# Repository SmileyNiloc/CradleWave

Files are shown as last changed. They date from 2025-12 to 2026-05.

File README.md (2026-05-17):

# CradleWave: Contactless Infant Vitals Monitoring 🍼📡


[]()
[]()
[]()
[]()

**CradleWave** is an end-to-end IoT monitoring system that leverages 60 GHz FMCW radar to measure an infant's heart rate and respiration—completely avoiding the privacy concerns and physical discomfort of traditional cameras, microphones, or wearables.

This repository contains the complete systems engineering effort encompassing a custom 4-layer PCB, ESP32-S3 FreeRTOS firmware, a containerized Python digital signal processing (DSP) pipeline, and a real-time Vue 3 dashboard.

## 🚀 Tech Stack Highlights

- **Hardware & Firmware:** ESP32-S3, Infineon XENSIV 60GHz Radar (BGT60TR13C), Custom 4-Layer PCB, C/C++, ESP-IDF, FreeRTOS
- **DSP & Data Pipeline:** Python (NumPy, SciPy), Docker Compose microservices, Redis, AWS IoT Core (MQTT over TLS)
- **Frontend & Database:** Vue 3, ECharts, Google Firestore, Firebase Hosting

## 💡 The Problem & Our Solution

Each year, thousands of infants in the US are affected by SIDS or sleep-related suffocation. Existing monitors are often uncomfortable, inconvenient, or limited in vital-sign coverage.

CradleWave targets contactless, continuous monitoring from a safe distance. The final prototype integrates an Infineon BGT60TR13C radar shield with a custom ESP32-S3 PCB to stream raw multi-dimensional radar data over WiFi. The data is processed via an algorithmic pipeline in the cloud to extract physiological vitals, which are then surfaced on a responsive web UI.

### Key Engineering Achievements

- Developed a high-bandwidth IoT pipeline using MQTT/TLS to stream raw binary radar data asynchronously from an ESP32 to AWS IoT Core.
- Built a multi-container Docker compose DSP microservice, orchestrating Python with Redis to filter out environmental noise.
- Designed and verified an algorithmic pipeline (using FFT, moving target indicators, and bandpass filters) that calculates BPM/RPM to +-5/+-3 accuracy points from noisy FMCW data.
- Built an end-to-end Vue.js SPA dynamically synced via Firestore, handling real-time data visualisations of signals at sub-second refresh rates.

## System Architecture

```mermaid
flowchart TD
    %% Clinical Calm Theme - Green Dominant
    classDef default fill:#CEE4C7,stroke:#FFFFFF,stroke-width:3px,color:#334155
    classDef storage fill:#F8F9F5,stroke:#CEE4C7,stroke-width:3px,color:#334155

    %% Style the connecting arrows to match the theme
    linkStyle default stroke:#A8CBA0,stroke-width:2px,color:#334155

    A["`**ESP32 Radar**
    Hardware sensor node collecting raw data`"] -->|Publish MQTT Message| B["`**AWS IoT Core MQTT**
    Managed cloud broker receiving data`"]

    B -->|Subscribed to MQTT topic| C("`**Ingestor Node**
    Retrieves and buffers incoming payloads`")

    C -->|Queued Frames| R("`**Redis**
    In-Memory Storage Container`")

    R -->|Queued Frames| D("`**Processor Node**
    Runs Signal Processing to find vitals signs`")

    D -->|Vital Signs| R

    R -->|Vitals Signs| E("`**Exporter Node**
    Formats output for database ingestion`")

    E -->|Write/Update| F[("`**Firestore Database**
    NoSQL document store for vital signs data`")]

    F -->|Real-Time Sync| G["`**Vue.js Web Dashboard**
    Frontend UI displaying live analytics`"]

    %% Apply storage theme to databases
    class R,F storage
```

## 🏗️ Project Architecture & Repositories

```
CradleWave/
├── CAD_Designs/                # Fusion360 3D Enclosure Designs
├── station_example_main.c      # ESP-IDF FreeRTOS Firmware Logic (Radar SPI + WiFi + MQTT)
├── local_testing/              # Local Docker Compose setup for iterating on MQTT and signal loops
├── mqtt_test/                  # Raw payload tests and Python MQTT test scripts
├── demo_board_python/          # (Legacy) Initial prototype using Infineon demo board + Raspberry Pi
│
└── webdev/
    ├── backend/                # Python / Docker Compose Pipeline
    │   ├── ingestor/           # AWS IoT MQTT Handler
    │   ├── processor/          # DSP Pipeline (SciPy, FFT, filtering)
    │   └── exporter/           # Formatting & Firestore synchronization
    │
    └── frontend/               # Vue 3 SPA Dashboard
        ├── src/components/     # EChart graphs and dynamic components
        └── package.json
```

## 💻 Developer Quick Start

### Hardware / Firmware Setup (ESP32-S3)

The custom firmware is built using the **ESP-IDF** (`station_example_main.c`).

1. Install **ESP-IDF** toolchain v5.x
2. Export your IDF path: `. $HOME/esp/esp-idf/export.sh`
3. Enter `idf.py build flash monitor`

### Backend Signal Pipeline Simulation

Test out the containerized DSP node logic without deploying to Oracle Cloud.

```bash
cd local_testing
docker-compose up --build
```

This spins up a local Redis container and triggers the processor node over local test CSV data.

### Web Dashboard

```bash
cd webdev/frontend
npm install
npm run serve
```

Navigate to `localhost:8080` check out the Vue 3 ECharts SPA.

## 📉 Digital Signal Processing Pipeline

The backend processor service runs the raw data arrays via NumPy/SciPy:

1. **Range-Doppler Mapping:** 2D FFT to convert the raw frame data to a velocity plot across the sensor range.
2. **Integration:** Strongest returns from the doppler map are summed to isolate primary target activity.
3. **Moving Target Indicator (MTI):** High-pass subtracts background static objects.
4. **Bandpass Filtering:** Narrows the resulting waveform down to expected physiological frequencies (e.g. 48-160 Hz bandwidth mapped back to realistic physiological RPM/BPM rates).
5. **Peak Estimation:** Analyzes moving windows of 20 seconds using arg-max estimations.

## ⚖️ Safety & Standards

- Developed beneath **FCC Part 15** emission guidelines (staying within the 57 - 71GHz unlicensed radar operations). System utilizes 8 dB transmitter with 3dB antenna gain remaining well under bounds.
- Deep tissue penetration avoids via sub-0.1W/m2 operation levels.
- Designed adhering to **IEC/UL62368C-1** keeping surface child-touch temperatures bounded through custom multi-layer GND-plane PCB pour routing layout techniques.

## Team

**University of Delaware - CPEG 498 Senior Design Project (2025-2026)**

- **Colin Aten**
- **Logan Blackburn**
- **Robert Koenig**

## Acknowledgments

- University of Delaware ECE Department

## License

This project is developed as part of the University of Delaware Electrical and Computer Engineering Senior Design program.

## References

1. Infineon BGT60TR13C Radar Sensor Documentation
2. FMCW Radar Signal Processing for Vital Signs Detection
3. Welch's Method for Power Spectral Density Estimation

---

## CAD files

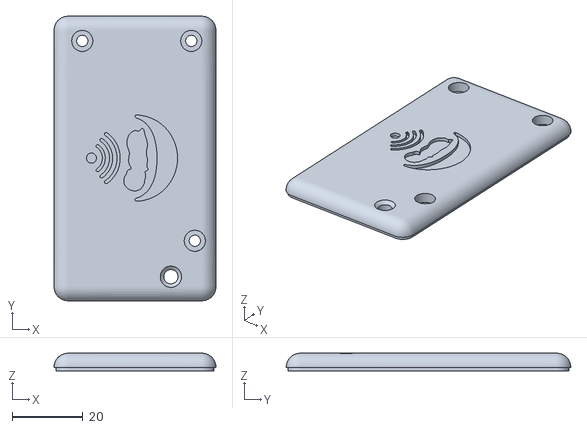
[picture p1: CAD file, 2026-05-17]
CAD_Designs/CradleWave_Custom_PCB_Top.stl
45.8 x 80.6 x 5.00

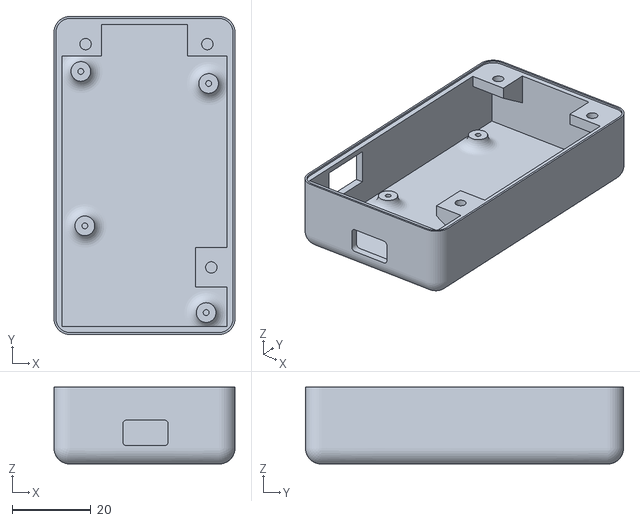
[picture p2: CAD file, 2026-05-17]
CAD_Designs/CradleWave_Custom_PCB_Bottom.stl
45.8 x 80.6 x 19.5

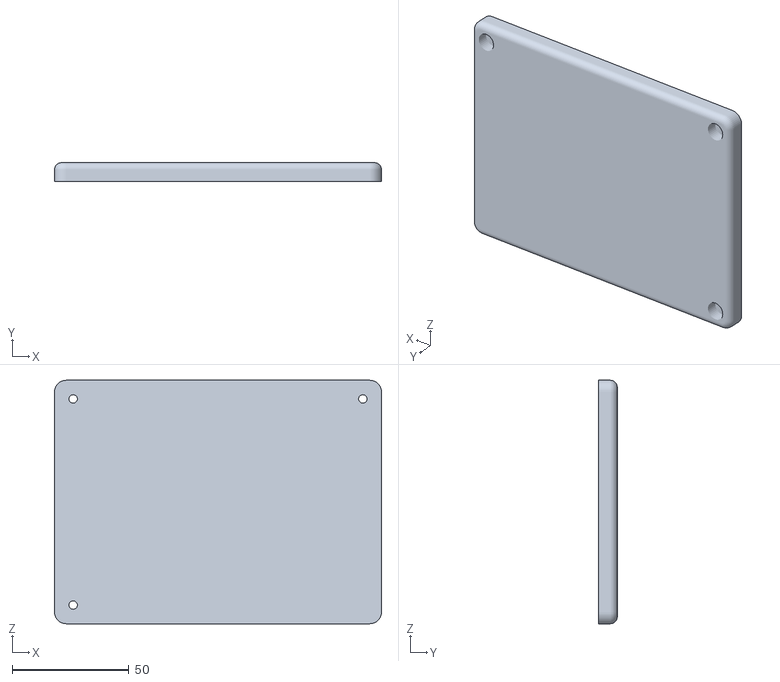
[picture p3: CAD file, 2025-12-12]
CAD_Designs/CradleWave_Case_Top v2.stl
140.1 x 8.00 x 104.3

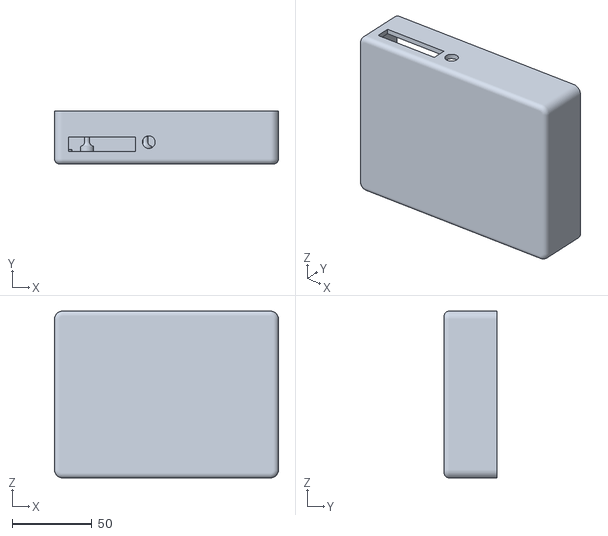
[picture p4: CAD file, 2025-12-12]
CAD_Designs/CradleWave_Case v5.stl
140.1 x 33.0 x 104.3

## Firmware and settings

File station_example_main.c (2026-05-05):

/*
 * Connects to WiFi, reads raw FMCW chirp data from BGT60TR13C over SPI,
 * and publishes binary frames to AWS IoT Core over MQTT/TLS.
 *
 * SPI protocol based on BGT60TR13C Datasheet V2.4.9, Section 5.
 */

#include <string.h>
#include <time.h>
#include "freertos/FreeRTOS.h"
#include "freertos/task.h"
#include "freertos/event_groups.h"
#include "esp_system.h"
#include "esp_mac.h"
#include "esp_wifi.h"
#include "esp_event.h"
#include "esp_log.h"
#include "nvs_flash.h"
#include "lwip/sockets.h"
#include "driver/gpio.h"
#include "mqtt_client.h"
#include "esp_netif_sntp.h"
#include "driver/spi_master.h"
#include "esp_heap_caps.h"

#include "lwip/err.h"
#include "lwip/sys.h"

// WiFi credentials
#define EXAMPLE_ESP_WIFI_SSID "UD Devices"
#define EXAMPLE_ESP_WIFI_PASS ""
#define EXAMPLE_ESP_MAXIMUM_RETRY  CONFIG_ESP_MAXIMUM_RETRY

// AWS IoT config
#define AWS_IOT_ENDPOINT "a1py3mdrrjrz1-ats.iot.us-east-1.amazonaws.com"
#define AWS_IOT_PORT 8883
#define MQTT_TOPIC "raw_sensor_data"
#define MQTT_CLIENT_ID "esp32s3-cradlewave-001"

// TLS certificates
extern const uint8_t aws_root_ca_pem_start[] asm("_binary_AmazonRootCA1_cer_start");
extern const uint8_t aws_root_ca_pem_end[] asm("_binary_AmazonRootCA1_cer_end");
extern const uint8_t certificate_pem_crt_start[] asm("_binary_CradleWave_ES32_cert_pem_start");
extern const uint8_t certificate_pem_crt_end[] asm("_binary_CradleWave_ES32_cert_pem_end");
extern const uint8_t private_pem_key_start[] asm("_binary_CradleWave_ES32_private_key_start");
extern const uint8_t private_pem_key_end[] asm("_binary_CradleWave_ES32_private_key_end");

// WiFi auth mode threshold
#if CONFIG_ESP_STATION_EXAMPLE_WPA3_SAE_PWE_HUNT_AND_PECK
#define ESP_WIFI_SAE_MODE WPA3_SAE_PWE_HUNT_AND_PECK
#define EXAMPLE_H2E_IDENTIFIER ""
#elif CONFIG_ESP_STATION_EXAMPLE_WPA3_SAE_PWE_HASH_TO_ELEMENT
#define ESP_WIFI_SAE_MODE WPA3_SAE_PWE_HASH_TO_ELEMENT
#define EXAMPLE_H2E_IDENTIFIER CONFIG_ESP_WIFI_PW_ID
#elif CONFIG_ESP_STATION_EXAMPLE_WPA3_SAE_PWE_BOTH
#define ESP_WIFI_SAE_MODE WPA3_SAE_PWE_BOTH
#define EXAMPLE_H2E_IDENTIFIER CONFIG_ESP_WIFI_PW_ID
#endif

#if CONFIG_ESP_WIFI_AUTH_OPEN
#define ESP_WIFI_SCAN_AUTH_MODE_THRESHOLD WIFI_AUTH_OPEN
#elif CONFIG_ESP_WIFI_AUTH_WEP
#define ESP_WIFI_SCAN_AUTH_MODE_THRESHOLD WIFI_AUTH_WEP
#elif CONFIG_ESP_WIFI_AUTH_WPA_PSK
#define ESP_WIFI_SCAN_AUTH_MODE_THRESHOLD WIFI_AUTH_WPA_PSK
#elif CONFIG_ESP_WIFI_AUTH_WPA2_PSK
#define ESP_WIFI_SCAN_AUTH_MODE_THRESHOLD WIFI_AUTH_WPA2_PSK
#elif CONFIG_ESP_WIFI_AUTH_WPA_WPA2_PSK
#define ESP_WIFI_SCAN_AUTH_MODE_THRESHOLD WIFI_AUTH_WPA_WPA2_PSK
#elif CONFIG_ESP_WIFI_AUTH_WPA3_PSK
#define ESP_WIFI_SCAN_AUTH_MODE_THRESHOLD WIFI_AUTH_WPA3_PSK
#elif CONFIG_ESP_WIFI_AUTH_WPA2_WPA3_PSK
#define ESP_WIFI_SCAN_AUTH_MODE_THRESHOLD WIFI_AUTH_WPA2_WPA3_PSK
#elif CONFIG_ESP_WIFI_AUTH_WAPI_PSK
#define ESP_WIFI_SCAN_AUTH_MODE_THRESHOLD WIFI_AUTH_WAPI_PSK
#endif

// GPIO pin assignments
#define LED_ENABLE  GPIO_NUM_37
#define LDO_ENABLE  GPIO_NUM_35
#define LED_GND     GPIO_NUM_15
#define PIN_MISO    GPIO_NUM_13 // S1_SPI_MISO
#define PIN_MOSI    GPIO_NUM_11 // S1_SPI_MOSI
#define PIN_CLK     GPIO_NUM_12 // S1_SPI_CLK
#define PIN_CS      GPIO_NUM_10 // S1_SPI_CSN
#define PIN_RST     GPIO_NUM_9  // S1_RST
#define PIN_IRQ     GPIO_NUM_14 // S1_IRQ
#define PIN_SPI_En  GPIO_NUM_8

// SPI host
#define BGT_SPI_HOST  SPI2_HOST

// BGT60TR13C register addresses (7-bit, per datasheet Section 4)
#define BGT60_REG_MAIN      0x00 // main control, FRAME_START lives here
#define BGT60_REG_ADC0      0x01 // MADC control
#define BGT60_REG_CHIP_ID   0x02 // chip ID, should read 0x000303
#define BGT60_REG_STAT1     0x03 // status register 1
#define BGT60_REG_PACR1     0x04 // PLL analog control 1
#define BGT60_REG_PACR2     0x05 // PLL analog control 2
#define BGT60_REG_SFCTL     0x06 // SPI & FIFO control, PREFIX_EN, FIFO_CREF
#define BGT60_REG_SADC_CTRL 0x07 // sensor ADC control
#define BGT60_REG_CSI_0     0x08
#define BGT60_REG_CSI_1     0x09
#define BGT60_REG_CSI_2     0x0A
#define BGT60_REG_CSCI      0x0B
#define BGT60_REG_CSDS_0    0x0C
#define BGT60_REG_CSDS_1    0x0D
#define BGT60_REG_CSDS_2    0x0E
#define BGT60_REG_CSCDS     0x0F
#define BGT60_REG_CSU1_0    0x10
#define BGT60_REG_CSU1_1    0x11
#define BGT60_REG_CSU1_2    0x12
#define BGT60_REG_CSC1      0x16
#define BGT60_REG_CSC2      0x1D
#define BGT60_REG_CSC3      0x24
#define BGT60_REG_CSC4      0x2B
#define BGT60_REG_CCR0      0x2C
#define BGT60_REG_CCR1      0x2D
#define BGT60_REG_CCR2      0x2E
#define BGT60_REG_CCR3      0x2F
#define BGT60_REG_PLL1_0    0x30
#define BGT60_REG_PLL1_1    0x31
#define BGT60_REG_PLL1_2    0x32
#define BGT60_REG_PLL1_3    0x33
#define BGT60_REG_PLL1_4    0x34
#define BGT60_REG_PLL1_5    0x35
#define BGT60_REG_PLL1_6    0x36
#define BGT60_REG_PLL1_7    0x37
#define BGT60_REG_PLL2_7    0x3F
#define BGT60_REG_PLL3_7    0x47
#define BGT60_REG_PLL4_7    0x4F
#define BGT60_REG_RFT1      0x56
#define BGT60_REG_UNK_0x5B  0x5B

/* BGT60TR13C init register table
    - FMCW chirp configuration for BGT60TR13C
    - contain both target register value and encoded address/RW header in high byte
    - bgt60_write_reg() masks data to bits 23-0 before transmitting
    - applied in sequence via bgt60_write_register_list() after MISO_HS_RD is cleared
    - list does not set FRAME_START, that's last step of bgt60_configure()
 */
typedef struct {
    uint8_t  addr;
    uint32_t data; //lower 24 bits are the real register value
} bgt60_reg_init_t;

static const bgt60_reg_init_t bgt60_init_list[] = {
    {BGT60_REG_MAIN     , 0x011e8270},
    {BGT60_REG_ADC0     , 0x03140210},
    {BGT60_REG_PACR1    , 0x09e967fd},
    {BGT60_REG_PACR2    , 0x0b0805b4},
    {BGT60_REG_SFCTL    , 0x0d1023ff},
    {BGT60_REG_SADC_CTRL, 0x0f010700},
    {BGT60_REG_CSI_0    , 0x11000000},
    {BGT60_REG_CSI_1    , 0x13000000},
    {BGT60_REG_CSI_2    , 0x15000000},
    {BGT60_REG_CSCI     , 0x17000be0},
    {BGT60_REG_CSDS_0   , 0x19000000},
    {BGT60_REG_CSDS_1   , 0x1b000000},
    {BGT60_REG_CSDS_2   , 0x1d000000},
    {BGT60_REG_CSCDS    , 0x1f000b60},
    {BGT60_REG_CSU1_0   , 0x21103c51},
    {BGT60_REG_CSU1_1   , 0x231ff41f},
    {BGT60_REG_CSU1_2   , 0x25700c63},
    {BGT60_REG_CSC1     , 0x2d000490},
    {BGT60_REG_CSC2     , 0x3b000480},
    {BGT60_REG_CSC3     , 0x49000480},
    {BGT60_REG_CSC4     , 0x57000480},
    {BGT60_REG_CCR0     , 0x5911be0e},
    {BGT60_REG_CCR1     , 0x5b5a3c0a},
    {BGT60_REG_CCR2     , 0x5d01f000},
    {BGT60_REG_CCR3     , 0x5f787e1e},
    {BGT60_REG_PLL1_0   , 0x61c72e83},
    {BGT60_REG_PLL1_1   , 0x63000393},
    {BGT60_REG_PLL1_2   , 0x650002b2},
    {BGT60_REG_PLL1_3   , 0x67000040},
    {BGT60_REG_PLL1_4   , 0x69000000},
    {BGT60_REG_PLL1_5   , 0x6b000000},
    {BGT60_REG_PLL1_6   , 0x6d000000},
    {BGT60_REG_PLL1_7   , 0x6f2d1d10},
    {BGT60_REG_PLL2_7   , 0x7f000100},
    {BGT60_REG_PLL3_7   , 0x8f000100},
    {BGT60_REG_PLL4_7   , 0x9f000100},
    {BGT60_REG_RFT1     , 0xad000000},
    {BGT60_REG_UNK_0x5B , 0xb7000000},
};

#define BGT60_INIT_LIST_LEN  (sizeof(bgt60_init_list) / sizeof(bgt60_init_list[0]))

// Frame dimensions
#define BGT60_NUM_CHIRPS     32
#define BGT60_NUM_SAMPLES    64
#define BGT60_TOTAL_SAMPLES  (BGT60_NUM_CHIRPS * BGT60_NUM_SAMPLES) // 2048

// 2 12-bit samples in every 24-bit FIFO word
// 2048 samples / 2 = 1024 FIFO words to read
#define BGT60_FIFO_WORDS     (BGT60_TOTAL_SAMPLES / 2) // 1024

// burst read transfer layout
// 4 + 4 + (1024 * 3) = 3080 bytes
#define BGT60_BURST_CMD_BYTES   4
#define BGT60_BURST_HDR_BYTES   4 // GSR0 (1) + DC padding (3)
#define BGT60_BURST_DATA_BYTES  (BGT60_FIFO_WORDS * 3) // 3072
#define BGT60_BURST_TOTAL_BYTES (BGT60_BURST_CMD_BYTES + BGT60_BURST_HDR_BYTES + BGT60_BURST_DATA_BYTES) // 3080

/* MQTT binary payload:
    - bytes(0 to 7) = uint64_t timestamp_ms (little-endian)
    - bytes(8 to end) = uint16_t samples, 1024 * 2 bytes = 2048 bytes
    - Total = 8200 bytes
 */
#define BGT60_FRAME_BYTES    (BGT60_TOTAL_SAMPLES * sizeof(uint16_t)) // 8192
#define MQTT_PAYLOAD_SIZE    (8 + BGT60_FRAME_BYTES) // 8200

//WiFi MQTT state
static EventGroupHandle_t s_wifi_event_group;
#define WIFI_CONNECTED_BIT  BIT0
#define WIFI_FAIL_BIT       BIT1
static int s_retry_num = 0;

static const char *TAG = "cradlewave";

static esp_mqtt_client_handle_t mqtt_client = NULL;
static bool mqtt_connected = false;

// SPI IRQ handles
static spi_device_handle_t bgt_spi;
static SemaphoreHandle_t   bgt_irq_sem;

/* BGT60TR13C SPI low-level register access:
    - matches Infineon's reference driver sensor-xensiv-bgt60trxx transaction
    - wire format (32 bits MSB first on SCLK):
        - bit(31 downto 25) = register address
        - bit(24) = RW (1 = write, 0 = read)
        - bit(23 downto 0) = data (write data on MOSI; MISO returns [GSR0(4b)][data(20b)]
*/

#define BGT60_SPI_WR_OP_MSK      0x01000000UL // bit 24 = RW
#define BGT60_SPI_REGADR_POS     25U
#define BGT60_SPI_REGADR_MSK     0xFE000000UL // bits 31..25 = addr
#define BGT60_SPI_DATA_MSK       0x00FFFFFFUL // bits 23..0  = data
#define BGT60_SPI_GSR0_MSK       0x0F000000UL // bits 27..24 = GSR0

// Reverse byte order of a 32-bit word, xensiv_bgt60trxx_platform_word_reverse()
static inline uint32_t bgt60_word_reverse(uint32_t x)
{
    return __builtin_bswap32(x);
}

// Low-level full-duplex transfer of 4 bytes, xensiv_bgt60trxx_platform_spi_transfer()
static esp_err_t bgt60_spi_xfer4(const void *tx, void *rx)
{
    spi_transaction_t t = {
        .length    = 32, // 4 bytes * 8 bits
        .tx_buffer = tx,
        .rx_buffer = rx,
    };
    return spi_device_transmit(bgt_spi, &t);
}

// Write a 24-bit value to a register, xensiv_bgt60trxx_set_reg()
static esp_err_t bgt60_write_reg(uint8_t addr, uint32_t data)
{
    WORD_ALIGNED_ATTR uint32_t w;
    w = ((uint32_t)addr << BGT60_SPI_REGADR_POS) & BGT60_SPI_REGADR_MSK;
    w |= BGT60_SPI_WR_OP_MSK;
    w |= (data & BGT60_SPI_DATA_MSK);
    w = bgt60_word_reverse(w);
    return bgt60_spi_xfer4(&w, NULL);
}

// Read a 24-bit register value, xensiv_bgt60trxx_get_reg()
static esp_err_t bgt60_read_reg(uint8_t addr, uint32_t *data_out)
{
    WORD_ALIGNED_ATTR uint32_t tx_w;
    WORD_ALIGNED_ATTR uint32_t rx_w = 0;

    tx_w = ((uint32_t)addr << BGT60_SPI_REGADR_POS) & BGT60_SPI_REGADR_MSK;
    // RW bit = 0 for read, data bits = don't care
    tx_w = bgt60_word_reverse(tx_w);

    esp_err_t ret = bgt60_spi_xfer4(&tx_w, &rx_w);
    if (ret != ESP_OK) {
        return ret;
    }

    rx_w = bgt60_word_reverse(rx_w);

    // Byte-swapped host-endian view:
    // bits(27 downto 24) = GSR0 error flags
    // bits(23 downto 0) = register data (per reference driver, mask with
    uint8_t gsr0 = (uint8_t)((rx_w & BGT60_SPI_GSR0_MSK) >> 24);
    // ignored errors
    if ((gsr0 & 0x0F) != 0x00 && (gsr0 & 0x0F) != 0x04 && (gsr0 & 0x0F) != 0x01 && (gsr0 & 0x0F) != 0x09) {
        ESP_LOGW(TAG, "read_reg addr=0x%02X GSR0 error flags: 0x%02X", addr, gsr0);
    }

    *data_out = rx_w & BGT60_SPI_DATA_MSK;
    return ESP_OK;
}

/* BGT60TR13C SPI burst FIFO read, xensiv_bgt60trxx_get_fifo_data()
    - 4-byte burst command + data payload, all under one CSn assertion
    - burst command encoding:
        - bits(31 downto 25) = 0x7F (burst command opcode)
        - bit(24) = 1 (RW: burst read uses command bit 24 = 1)
        - bits(23 downto 17) = SADDR (start address, FIFO register)
        - bit(16) = 0 (RWB: burst read data direction, 0 = read)
        - bits(15 downto 9) = NBURSTS (0 = unbounded, master stops by deasserting CS)
        - bits(8 downto 0) = reserved
    - FIFO register is at 0x60 (XENSIV_BGT60TRXX_REG_FIFO_TR13C)
        - resulting command word = 0xFFC0_0000.
*/

#define BGT60_SPI_BURST_MODE_CMD         0xFF000000UL
#define BGT60_SPI_BURST_MODE_SADR_POS    17U
#define BGT60_REG_FIFO_TR13C             0x60U

static esp_err_t bgt60_burst_read_fifo(uint16_t *samples_out)
{
    uint8_t *tx = heap_caps_calloc(BGT60_BURST_TOTAL_BYTES, 1, MALLOC_CAP_DMA);
    uint8_t *rx = heap_caps_calloc(BGT60_BURST_TOTAL_BYTES, 1, MALLOC_CAP_DMA);
    if (!tx || !rx) {
        free(tx);
        free(rx);
        return ESP_ERR_NO_MEM;
    }

    // FIFO register for BGT60TR13C = 0x60
    uint8_t fifo_reg = BGT60_REG_FIFO_TR13C;

    // build burst command in host-endian, then byte-swap into first 4 bytes of TX buffer
    uint32_t cmd = BGT60_SPI_BURST_MODE_CMD | ((uint32_t)fifo_reg << BGT60_SPI_BURST_MODE_SADR_POS);
    cmd = bgt60_word_reverse(cmd);
    memcpy(tx, &cmd, 4);
    // tx[4..end] stays 0x00, any value on MOSI is valid during data phase

    spi_transaction_t t = {
        .length = BGT60_BURST_TOTAL_BYTES * 8,
        .tx_buffer = tx,
        .rx_buffer = rx,
    };
    esp_err_t ret = spi_device_transmit(bgt_spi, &t);

    if (ret == ESP_OK) {
        // rx(0) = GSR0 (clocked out during command byte 0)
        // rx(1 to 3) = don't-care bytes from command phase
        // rx(4 to end) = FIFO data, 3 bytes per 24-bit word, MSB first
        uint8_t gsr0 = rx[0];
        if ((gsr0 & 0x0F) != 0x00 && (gsr0 & 0x0F) != 0x04 && (gsr0 & 0x0F) != 0x01 && (gsr0 & 0x0F) != 0x09) {
            ESP_LOGW(TAG, "Burst read GSR0 error flags: 0x%02X", gsr0);
        }

        int out_idx = 0;
        for (int i = 0; i < BGT60_FIFO_WORDS && out_idx < BGT60_TOTAL_SAMPLES; i++) {
            int base = BGT60_BURST_HDR_BYTES + (i * 3);
            uint32_t word = ((uint32_t)rx[base] << 16)
                          | ((uint32_t)rx[base + 1] << 8)
                          |  (uint32_t)rx[base + 2];
            // upper 12 bits = first sample
            // lower 12 bits = second sample
            samples_out[out_idx++] = (uint16_t)((word >> 12) & 0xFFF);
            samples_out[out_idx++] = (uint16_t)( word & 0xFFF);
        }
    }

    free(tx);
    free(rx);
    return ret;
}

/* BGT60TR13C hardware reset, xensiv_bgt60trxx_hard_reset():
    - Sequence:
        1. RST high, CSn high (idle state)
        2. T_CS_BRES > 100 ns before RST low (wait)
        3. RST low (reset asserted)
        4. T_RES > 1000 ns held low (wait)
        5. RST high (reset released)
        6. T_CS_ARES > 100 ns before SPI (wait)
*/
static void bgt60_hw_reset(void)
{
    gpio_set_direction(PIN_RST, GPIO_MODE_OUTPUT);

    // RST high, CSn high (idle)
    gpio_set_level(PIN_RST, 1);
    gpio_set_level(PIN_CS,  1);
    vTaskDelay(pdMS_TO_TICKS(1));

    // RST low (assert reset)
    gpio_set_level(PIN_RST, 0);
    vTaskDelay(pdMS_TO_TICKS(1));

    // RST high (release reset)
    gpio_set_level(PIN_RST, 1);
    vTaskDelay(pdMS_TO_TICKS(1));
    // Chip is now in Deep Sleep, ready to accept SPI commands
}

/* BGT60TR13C chip ID layout & soft reset, xensiv_bgt60trxx_soft_reset():
    - CHIP_ID (24-bit register 0x02) layout:
        - bits(23 downto 8) = DIGITAL_ID (0xFFFF00)
        - bits(7 downto 0) = RF_ID (0x0000FF)
    - For BGT60TR13C DIGITAL_ID = 3, RF_ID = 3 -> CHIP_ID = 0x000303
    - SFCTL (0x06) layout:
        - bits(23 downto 19) = RSVD (reset = 14B)
        - bit(18) = PREFIX_EN
        - bit(17) = LFSR_EN
        - bit(16) = MISO_HS_RD (reset = 1B)
        - bits(15 downto 14) = RSVD
        - bit(13) = FIFO_LP_MODE
        - bits(12 downto 0 = FIFO_CREF (max 8191)
    - CRITICAL: MISO_HS_RD = 1 at reset means  chip drives MISO on rising edge of SCLK, 
      which is incompatible with standard SPI mode 0 sampling. Must write SFCTL with 
      MISO_HS_RD = 0 as first SPI transaction (before any read attempt) if running at 
      SPI clock < 25 MHz with ESP32 in mode 0. Writes work fine even with bad MISO 
      timing because they don't depend on MISO.
*/

#define BGT60_REG_CHIP_ID_DIGITAL_ID_MSK   0x00FFFF00UL
#define BGT60_REG_CHIP_ID_DIGITAL_ID_POS   8U
#define BGT60_REG_CHIP_ID_RF_ID_MSK        0x000000FFUL
#define BGT60_REG_CHIP_ID_RF_ID_POS        0U
#define BGT60_CHIP_ID_TR13C                0x000303UL

#define BGT60_REG_MAIN_FRAME_START_MSK     0x00000001UL
#define BGT60_RESET_SW                     0x00000002UL // SW reset in MAIN
#define BGT60_RESET_FSM                    0x00000004UL // FSM reset in MAIN
#define BGT60_RESET_TIMEOUT                1000U

// SFCTL bit field positions/masks (datasheet Section 4.8)
#define BGT60_SFCTL_FIFO_CREF_POS          0U
#define BGT60_SFCTL_FIFO_CREF_MSK          0x00001FFFUL // bits(12 downto 0)
#define BGT60_SFCTL_FIFO_LP_MODE_MSK       0x00002000UL // bit(13)
#define BGT60_SFCTL_MISO_HS_RD_MSK         0x00010000UL // bit(16)
#define BGT60_SFCTL_LFSR_EN_MSK            0x00020000UL // bit(17)
#define BGT60_SFCTL_PREFIX_EN_MSK          0x00040000UL // bit(18)
#define BGT60_SFCTL_RSVD_DEFAULT           0x00700000UL // bits(22 downto 19) reset to 14B = 1110b; bit 23 reset unknown

__attribute__((unused))
static esp_err_t bgt60_soft_reset(uint32_t reset_type)
{
    uint32_t tmp;
    esp_err_t err = bgt60_read_reg(BGT60_REG_MAIN, &tmp);
    if (err != ESP_OK) return err;

    tmp |= reset_type;
    err = bgt60_write_reg(BGT60_REG_MAIN, tmp);
    if (err != ESP_OK) return err;

    // poll reset bit until chip clears it
    for (uint32_t timeout = BGT60_RESET_TIMEOUT; timeout > 0; --timeout) {
        err = bgt60_read_reg(BGT60_REG_MAIN, &tmp);
        if (err == ESP_OK && (tmp & reset_type) == 0U) {
            vTaskDelay(pdMS_TO_TICKS(1));
            return ESP_OK;
        }
    }
    ESP_LOGE(TAG, "Soft reset (type 0x%08lX) timed out", (unsigned long)reset_type);
    return ESP_ERR_TIMEOUT;
}

/* Write SFCTL with known-good value, MUST be first SPI operation
    - MISO_HS_RD = 0 (low-speed MISO, falling-edge output)
    - PREFIX_EN = 0 (no metadata header in FIFO)
    - FIFO_CREF = fifo_cref (IRQ when FIFO level exceeds this)
    - RSVD bits = preserved at their reset value 
*/
static esp_err_t bgt60_write_sfctl(uint32_t fifo_cref, bool prefix_en)
{
    uint32_t val = BGT60_SFCTL_RSVD_DEFAULT;
    val |= (fifo_cref << BGT60_SFCTL_FIFO_CREF_POS) & BGT60_SFCTL_FIFO_CREF_MSK;
    if (prefix_en) val |= BGT60_SFCTL_PREFIX_EN_MSK;
    // MISO_HS_RD left at 0
    return bgt60_write_reg(BGT60_REG_SFCTL, val);
}

// apply full init register list (bgt60_init_list[])
static esp_err_t bgt60_write_register_list(void)
{
    for (size_t i = 0; i < BGT60_INIT_LIST_LEN; i++) {
        esp_err_t err = bgt60_write_reg(bgt60_init_list[i].addr,
                                        bgt60_init_list[i].data);
        if (err != ESP_OK) {
            ESP_LOGE(TAG, "Register list write failed at index %u "
                          "(addr=0x%02X): %d",
                     (unsigned)i, bgt60_init_list[i].addr, err);
            return err;
        }
    }
    return ESP_OK;
}
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
void app_main(void)
{
    // NVS init (required by WiFi driver)
    esp_err_t ret = nvs_flash_init();
    if (ret == ESP_ERR_NVS_NO_FREE_PAGES || ret == ESP_ERR_NVS_NEW_VERSION_FOUND) {
        ESP_ERROR_CHECK(nvs_flash_erase());
        ret = nvs_flash_init();
    }
    ESP_ERROR_CHECK(ret);

    if (CONFIG_LOG_MAXIMUM_LEVEL > CONFIG_LOG_DEFAULT_LEVEL) {
        esp_log_level_set("wifi", CONFIG_LOG_MAXIMUM_LEVEL);
    }

    uint8_t mac[6];
    esp_read_mac(mac, ESP_MAC_WIFI_STA);
    ESP_LOGI(TAG, "MAC: %02x:%02x:%02x:%02x:%02x:%02x",
             mac[0], mac[1], mac[2], mac[3], mac[4], mac[5]);

    // 1. connect to WiFi
    wifi_init_sta();

    // 2. sync real-world time (needed for valid MQTT timestamps)
    sync_time();

    // 3. start MQTT connection to AWS IoT Core
    mqtt_start();

    // 4. power on the BGT60TR13C shield
    //    LDO_ENABLE must be asserted before SPI init so chip has power
    gpio_set_direction(LDO_ENABLE, GPIO_MODE_OUTPUT);
    gpio_set_level(LDO_ENABLE, 1);
    vTaskDelay(pdMS_TO_TICKS(10)); // allow LDO to stabilise

    gpio_set_direction(PIN_SPI_En, GPIO_MODE_OUTPUT);
    gpio_set_level(PIN_SPI_En, 0);

    gpio_set_direction(LED_ENABLE, GPIO_MODE_OUTPUT);
    gpio_set_level(LED_ENABLE, 1);
    gpio_set_direction(LED_GND, GPIO_MODE_OUTPUT);
    gpio_set_level(LED_GND, 0);

    // 5. init SPI bus and device
    bgt60_spi_init();

    // 6. hardware reset
    bgt60_hw_reset();

    // 7. verify SPI comms, software-reset chip, configure FIFO, start frames
    bgt60_configure();

    // 8. configure IRQ input
    bgt60_irq_init();

    // 9. start radar read + publish task
    xTaskCreate(radar_publish_task, "radar_pub", 8192, NULL, 5, NULL);

    ESP_LOGI(TAG, "Returned from app_main()");
}

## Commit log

2025-09-18 Framework for web server: docker conatiners for vue frontend and FastAPI backend
2025-10-29 Working on websocket for arduino and backend
2025-10-29 working websocket on arduino mkr wifi 1010
2025-11-07 Added websocket funcitonality to filtered.py through new library websockets.py, updated backend to handled data
2025-11-11 will now send the initial filtered data collected
2025-11-12 adopted storing by devices not users, will be more flexible long term
2025-11-12 added imporved layout for selecting devices and sessions
2025-11-12 updated to use device not user on the board and backend
2025-11-13 updated display to accurately show both heart rate and radar frames
2025-11-13 removed depreciated folder: "/arduino" we no longer are using an arduino in the project due its lack of ability to effectively interface with the demo board
2025-11-18 test this without threadpools
2025-12-08 Added filtered hr and breathing with no plot(for raspi) and updated tootip on hrGraph
2025-12-12 CAD models for prototype
    [CradleWave_Case v5.stl, CradleWave_Case_Top v2.stl]
2025-12-12 Upload CAD Files
    [CradleWave_Case v5.stl, CradleWave_Case_Top v2.stl]
2026-03-10 Created test case and changed dockerfiles
2026-04-02 Added prints and changed exporter to actually get google key
2026-04-07 Chnaged to handle more realistic test case of data, automatically sends to firestore
2026-04-08 REmoved unneccessary prints
2026-04-23 Handling normalized data from board
2026-04-25 Updated SignalProcessor.py to current version.
2026-05-04 Added filtered_breath and filtered_heart
2026-05-04 Updated handling of filtered heart and breath
2026-05-04 Sending array of filtered breath instead of 1 point
2026-05-05 REverted processor to still sending filtered data
2026-05-14 Updated filtered graph
2026-05-16 Uploaded Final Prototype Files
    [CradleWave_Custom_PCB_Bottom.stl, CradleWave_Custom_PCB_Top.stl]
